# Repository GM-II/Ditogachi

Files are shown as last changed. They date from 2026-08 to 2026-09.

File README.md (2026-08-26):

# Ditogachi

<p align="center">
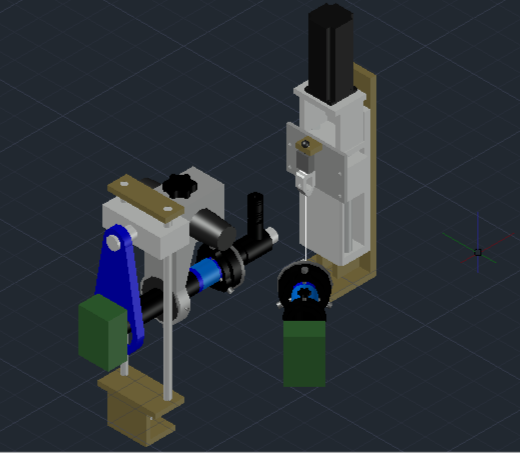
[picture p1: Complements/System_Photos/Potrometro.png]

</p>

## Open-Hardware System for Micrometric Deformation Measurement

This project presents the design and development of an open-hardware system that includes an extensometer capable of accurately measuring mechanical deformations at the micrometric scale, along with a set of open-source algorithms optimized for image analysis and the use of computer vision for the correct interpretation of the acquired data.

The system is intended for laboratory applications, teaching, and research. Priority is given to reproducibility, low cost, and easy access to the materials required for fabrication.

The source codes shared below, together with the referenced links and supporting materials under development, aim to enable anyone to build their own device for the analysis of stress, strain, and failure mechanisms.

This project combines Arduino and Python code.

## System Overview

<p align="center">
  
</p>

<p align="center">
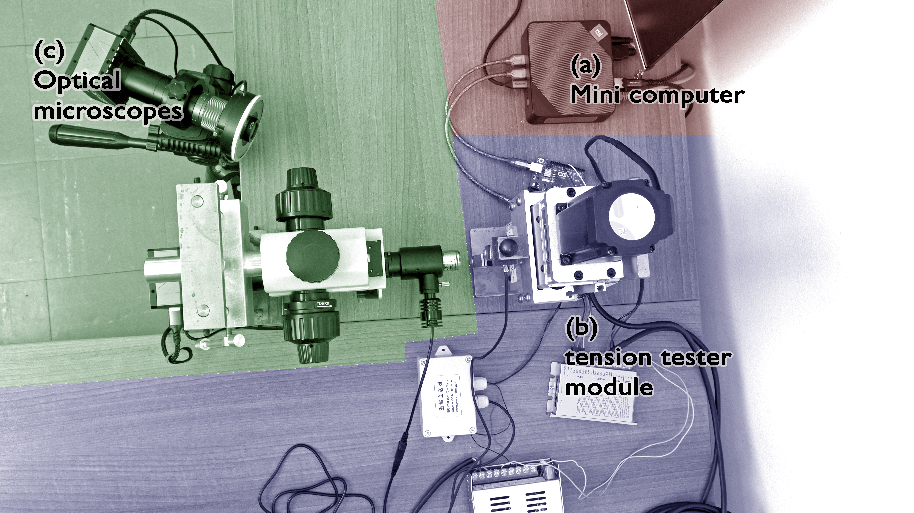
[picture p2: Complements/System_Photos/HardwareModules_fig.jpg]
  
</p>

<p align="center">
  
</p>

<p align="center">
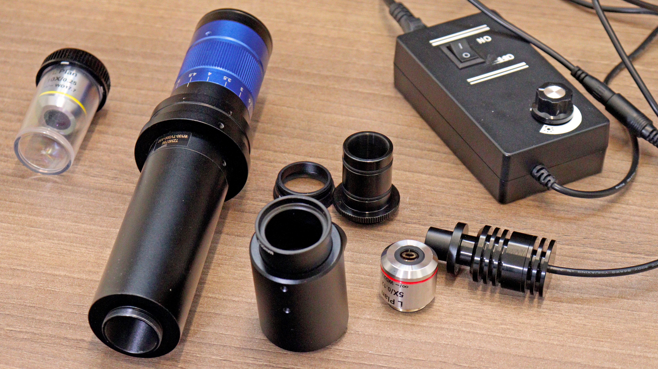
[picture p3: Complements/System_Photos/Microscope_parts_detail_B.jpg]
  
</p>

<p align="center">
  
</p>

*General view of the system, tensile module, microscopy system, and control electronics.*

## Repository content

- [`Build_Instruction`](./Build_Instruction/)
  Step-by-step instructions for the fabrication and assembly of the device.
  
- [`Operation_Instruction`](./Operation_Instruction/)
  Guidelines for proper use of the device, including calibration and safe operation.

- [`Bill_of_materials.md`](./Bill_of_materials.md)  
  Complete list of components, suppliers, and estimated costs.

- [`Software`](./Software/)
  Source code and scripts for data acquisition and analysis. Versions range from early alpha releases to version 2.0 of the code.

- [`Design_Files`](./Design_Files/) 
  Technical standards and references used in the design process (.stl files).

- [`Results`](./Results/)
  Experimental results obtained for the samples: force–elongation plots for each sample material.

- [`Complements/`](./Complements/)
  
  Supplementary documentation, including load cell characterization results and additional photographs of the system.

- [`Research_Output/`](./Research_Output/)
  
  Thesis manuscript and appendices documenting the first reported version of the system, provided as background and historical reference.

## Requirements

- 3D printer / access to a mechanical fabrication workshop
- Electronic components listed in the BOM
- Basic knowledge of instrumentation and electronics
- Software: Python (with required libraries: cv2, numpy, time, openpyxl, datetime, serial, os) / Arduino

## Instructions 

1. Consult the file [`Bill_of_materials.md`](./Bill_of_materials.md)).
2. Follow the construction instructions provided in [`Build_Instruction`](./Build_Instruction/).
3. Carefully review [`Operation_Instruction`](./Operation_Instruction/)) before operating the device.
4. Upload the firmware (.ino files) to the microcontrollers and run the Python scripts included in [`Software`](./Software/).

## Quick operation guide

1. **Setup**  
   Ensure the device is correctly assembled and all electrical connections
   are properly secured.

2. **Power on**  
   Connect the power supply and switch on the system.

3. **Operation**  
   Place the sample according to the specified orientation and initiate
   the measurement sequence using the provided software.

4. **Data acquisition**  
   Monitor real-time data on the interface and save measurement files
   after completion.

5. **Shutdown**  
   Stop the measurement, power off the device, and disconnect the power supply.

⚠️ **Important:**  
This section provides a high-level overview only.  
For calibration, safety precautions, and detailed operation procedures,
refer to [`Operation_instruction`](./Operation_instruction/).

## Project Status

- Functional prototype validated for laboratory use.
- Documentation is currently under development.
- Open to contributions.

## Licenses


###### Documentation
<a href="https://github.com/GM-II/Ditogachi">Ditogachi's Documentation</a> © 2026 by <a href="https://github.com/GM-II">GM-II</a> is licensed under <a href="https://creativecommons.org/licenses/by/4.0/">Creative Commons Attribution 4.0 International</a>

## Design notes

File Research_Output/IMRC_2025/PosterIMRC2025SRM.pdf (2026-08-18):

Heterogeneous Material Stress-Strain and Failure Analysis.

## Computer vision system for non-contact stress-strain assessment and failure mechanism analysis in tension tests of materials with heterogeneous microstructure

## Adquisición

Subsistema óptico de resolución alta: Zoom óptico con lente Barlow, cámara digital de alta velocidad y software de captura en tiempo real. Subsistema óptico microscópico: Microscopía con lentes de aumento variable y sistema de iluminación control de intensidad.

# Abstract

In this contribution we present a tension test system comprised of an open hardware testing machine and a set of open-source computer vision algorithms for non-contact stress-strain assessment.
The hardware is a homemade equipment customized for micro-tension experiments with maximum load of 50 kgf. We present a detailed set of building instructions, where the cost of the materials bill is around 1500 USD, a set of experiments evaluating the machine performance and limitations, mechanical test characterization for a wide set of materials, including those with heterogeneous microstructure distribution as well as reference materials for interlaboratory comparison.

# Materials and Methods

## System Environments

The overall system was designed to integrate three environments that, when coupled and synchronized, form a unified whole capable of performing deformation analysis and failure mechanism assessments: • Uniaxial tension generation and hardware control. • Image acquisition

- Computational control

Figure 1: System Environments.

# Results and Analysis

# Conclusion

- The prototype is an innovative alternative for the analysis of heterogeneous materials. Its results are promising, though optimization is required to expand its application across different study contexts. It shows strong potential for analyzing deformations and failure mechanisms.

# Acknowledgements

The authors acknowledge the structural support provided by the Universidad Nacional de Colombia (National University of Colombia), Colombia. We also thank Edison Ferney Abril Romero and Jhon Jairo Fajardo Toledo for their generous help in the development of the mechanical system, José Alfredo Gómez Mateus for his guidance on the basic understanding of the DIC protocols, and Serena Triviño Saenz for her collaboration in the experimental method characterization and validation. This Project belongs to the research hub with Hermes code 60225.

# References

For complete project references, scan the QR code.

Authors: Santiago Rosas Mogollón - srosasm@unal.edu.co Carlos Mario Garzón Ospina - cmgarzono@unal.edu.co Grupo de Microscopía Electrónica - Programa de Pregrado en Física

Figure 2: Assay on cupper sample.

Figure 3: Test specimens: Stainless steel on copper, tissue scaffolds, and biopolymers (from left to right).

Below, Figures 4, 5, and

### 6 show both the interface

operation and the results
of deformations and
failure mechanisms.

Figure 6: Elongation Tension Curves.

Figure 5: Failure mechanism in copper with steel couting.

Figure 4: Stress-strain assay in bovine collagen scaffold.

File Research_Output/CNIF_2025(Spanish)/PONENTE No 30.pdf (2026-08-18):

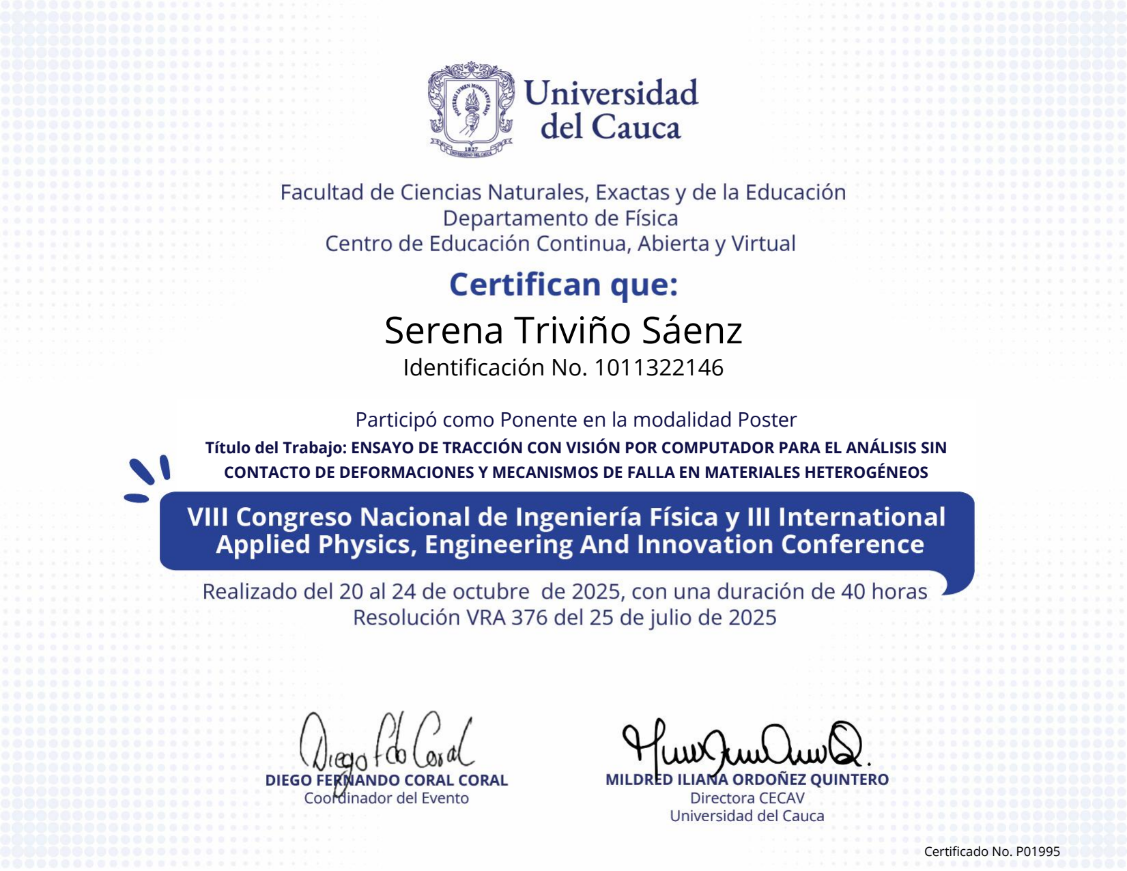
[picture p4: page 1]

# Serena Triviño Sáenz

## Identificación No. 1011322146

Certificado No. P01995

### Participó como Ponente en la modalidad Poster

Título del Trabajo: ENSAYO DE TRACCIÓN CON VISIÓN POR COMPUTADOR PARA EL ANÁLISIS SIN CONTACTO DE DEFORMACIONES Y MECANISMOS DE FALLA EN MATERIALES HETEROGÉNEOS

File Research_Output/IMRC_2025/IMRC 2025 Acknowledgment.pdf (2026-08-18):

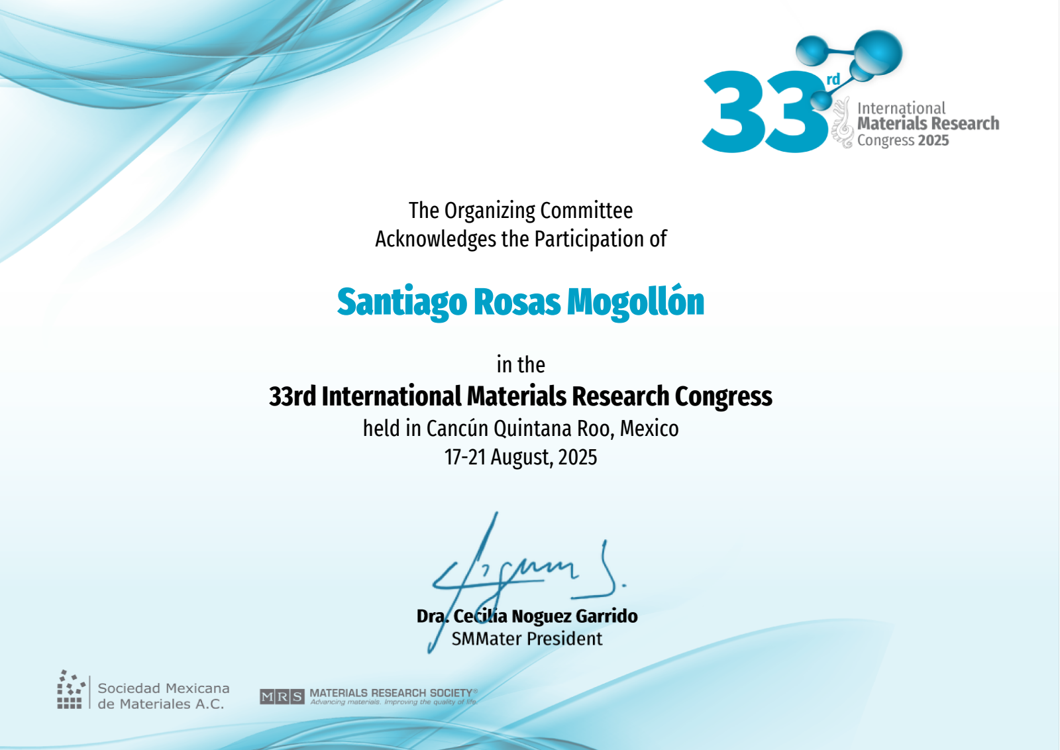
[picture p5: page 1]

The Organizing Committee
Acknowledges the Participation of

## Santiago Rosas Mogollón

in the

### 33rd International Materials Research Congress

held in Cancún Quintana Roo, Mexico 17-21 August, 2025

Powered by TCPDF (www.tcpdf.org)

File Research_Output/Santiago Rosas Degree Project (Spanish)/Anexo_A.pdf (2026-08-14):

## Anexo A

Santiago Rosas Mogollón

Marzo 2025

## 1. Control y Configuración del Motor y Driver

Para el control tanto del motor como del Driver se realizó una revisión a fondo de los manuales puestos a disposición del público por Rtelligent. En ellos se especifican tanto el modo de operación de las palancas del Driver como las diferentes opciones de micro pasos que se pueden obtener con las combinaciones de Estados encendido o apagado de los mismos además de este se especifican las conexiones del motor del Driver qué fuente requieran el tipo de señal que aceptan especificaciones técnicas y una guía sobre las señales de salida del Driver.[1][2]

### 1.1. Configuración de las Palancas de Selección (Switches)

Sobre las palancas de la sw5 a la sw8 modifican el modo de operación del Driver:

La palanca sw5 modifica la dirección del motor manualmente.

La palanca sw6 apaga o enciende la función de filtro de pulso.

La palanca sw7 selecciona el modo de pulso que se va a tomar si es un modo de pulso simple o un modo de pulso doble. Para el montaje se utilizó el modo de pulso simple.

La palanca sw8 controla si el motor está en modo lazo cerrado o abierto, el lazo abierto puede ser utilizado para una prueba inicial del motor.

Así mismo, las palancas de la sw1 hasta la sw4 permiten controlar los pulsos por Revolución, que no son más que los micro pasos en los que se pueden dividir los pasos nominales del motor. Para el motor 57A3ED que se utilizó, los pasos nominales eran 200, es decir, se necesitan 200 pulsos para dar un giro completo. Con respecto a la configuración utilizada de pulsos/rev, se seleccionó la mayor posible de 40,000 pulsos/rev, según como se indica tanto en el manual del Driver T60 como en la placa del mismo donde se encuentran todas las configuraciones posibles del Driver.

### 1.2. Conexiones del Sistema

En cuanto a las conexiones, basta con entender las conexiones del Driver para conseguir realizar el correcto ensamble del sistema. El Driver se divide en cuatro secciones de conexión:

1. VDC / Alimentación: Corresponde a la conexión hacia la fuente de alimentación. En este montaje se usó una fuente Drok de voltaje variable a 24 voltios.
2. Motor: Es la conexión directa con el stepper servomotor 57A3ED. Esta puede ser encontrada en la calcomanía de información del motor. En este caso la conexión es:

A+: Rojo

A-: Azul

B+: Verde

B-: Negro

3. Encoder: Tiene una conexión estandarizada para el Driver, la cual está distribuida de la siguiente manera:

EB+: Verde

EB-: Amarillo

EA+: Marrón

EA-: Blanco

Vcc: Rojo

GND: Azul

4. Signal: Son las conexiones para el control del pulso suministrado, el cual controla el avance del motor y su dirección. La conexión realizada fue:

PUL+ , DIR+ y ENA- al pin 9 PWM del Arduino Uno.

PUL- , DIR- y ENA+ al pin GND digital del mismo Arduino Uno.

Este Arduino fue programado con el código presentado en el Apéndice A.

### 1.3. Parámetros de Velocidad y Desplazamiento

Finalmente, la velocidad del motor se estableció en la más baja posible, la cual corresponde a 0,005 revoluciones por segundo. Dado el paso del actuador lineal de 5 mm por revolución, se obtiene un desplazamiento relativo entre mordazas de 0,025 mm cada segundo. Esto se logró generando un pulso cuadrado de 250 Hz y un 50 % de ciclo de trabajo.

## Apéndice A: Código Arduino

El siguiente código fue implementado en la plataforma Arduino para el control de la frecuencia de los pulsos enviados al Driver:

1 | // Definir el pin donde se g e n e r a r | el pulso
2 | const int pinPulso = 9; | // Pin 9 es v l i d o en Arduino Uno
3 | // Variable para almacenar la frecuencia deseada (en Hz)
4 | int frecuencia = 0; | // Frecuencia inicial

5

6
7 | // Variable para almacenar el p e r o d o del pulso (en microsegundos )
8 | unsigned long periodo ;

9
10 | void setup () {
11 | // Configurar el pin como salida
12 | pinMode ( pinPulso , OUTPUT ) ;
13 | // Iniciar la c o m u n i c a c i n serial
14 | Serial . begin (115200) ;
15 | // Calcular el p e r o d o inicial
16 | periodo = 1000000 / frecuencia ; | // 1 segundo = 1 ,000 ,000
microsegundos

17 }

18
19 | void loop () {
20 | if ( Serial . available () > 0) {
21 | String input = Serial . readStringUntil (’\n’) ;

22
23 | if ( input == " STOP ") {
24 | // Detener completamente los pulsos
25 | digitalWrite ( pinPulso , LOW ) ;
26 | } else {
27 | // Procesar como frecuencia
28 | frecuencia = input . toInt () ;
29 | if ( frecuencia > 0) {
30 | periodo = 1000000 / frecuencia ;
31 | }
32 | }
33 | }

34
35 | if ( frecuencia > 0) { | // Solo generar pulsos si frecuencia > 0
36 | digitalWrite ( pinPulso , HIGH ) ;
37 | delayMicroseconds ( periodo / 2) ;
38 | digitalWrite ( pinPulso , LOW ) ;
39 | delayMicroseconds ( periodo / 2) ;
40 | } else {
41 | digitalWrite ( pinPulso , LOW ) ;
42 | }
43 | }

## Referencias

[1] Rtelligent. | 2 phase closed loop stepper drive factory - china 2 phase closed
loop stepper drive manufacturers, suppliers. | https://www.rtelligentglobal.com/
2-phase-closed-loop-stepper-drive-oplen-loop-stepper-system/. Accedido: 11 de marzo de 2025.
[2] Rtelligent. | Wholesale | phase | closed | loop | stepper | motor | 57 | se-
ries | factory | and | suppliers. | https://www.rtelligentglobal.com/
phase-closed-loop-stepper-motor-57-series-product/. | Accedido: 11 de marzo
de 2025.

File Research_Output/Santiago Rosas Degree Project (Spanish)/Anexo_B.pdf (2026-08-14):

Anexo B: Caracterización de la Celda de Carga de 50 Kg.

### 1. Introducción

Este anexo describe la metodología empleada para caracterizar la celda de carga de 50 Kg integrada en la máquina. El análisis incluye la determinación de la relación entre la fuerza aplicada y la señal de salida, así como la evaluación de la linealidad en el rango de trabajo. Los resultados garantizan la precisión de las mediciones obtenidas durante las pruebas experimentales.

### 2. Materiales y Métodos

### 2.1. Equipo Utilizado

- Celda de carga: Modelo DYLY106, con una capacidad nominal máxima de 50 kg, una salida nominal de 2.0mV/V, y una precisión de +/- 0.1%.
- Transmisor amplificador de celda de carga: Se seleccionó un modelo WXD-D70 (JY-S60), optimizado para este tipo de celda de carga. El dispositivo acepta una señal de entrada con sensibilidad de sensor de 2.0 mV/V hasta 20mV y proporciona una salida DC de 0–5V / 0–10 V / 4–20 mA
- Fuente de alimentación: 24 V.
- Sistema de adquisición de datos: interfaz basada en Arduino con software de caracterización personalizado.
- Una prensa vertical con una carga de compresión inicial de 4.04 Kg.
- Un gancho de 0.76 Kg.
- Patrones de calibración: un conjunto de pesas de precisión de 1, 2, 4 y 10 Kg, previamente verificadas mediante una báscula digital calibrada (OHAUS Ranger 3000).

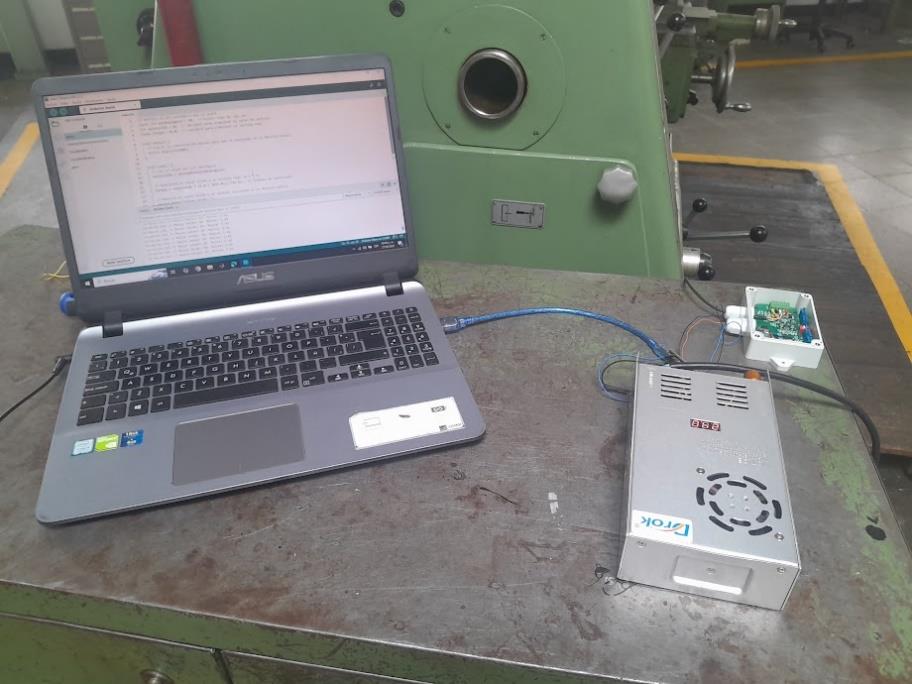
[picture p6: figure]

Fig 1. Hardware para la caracterización de la celda de carga.

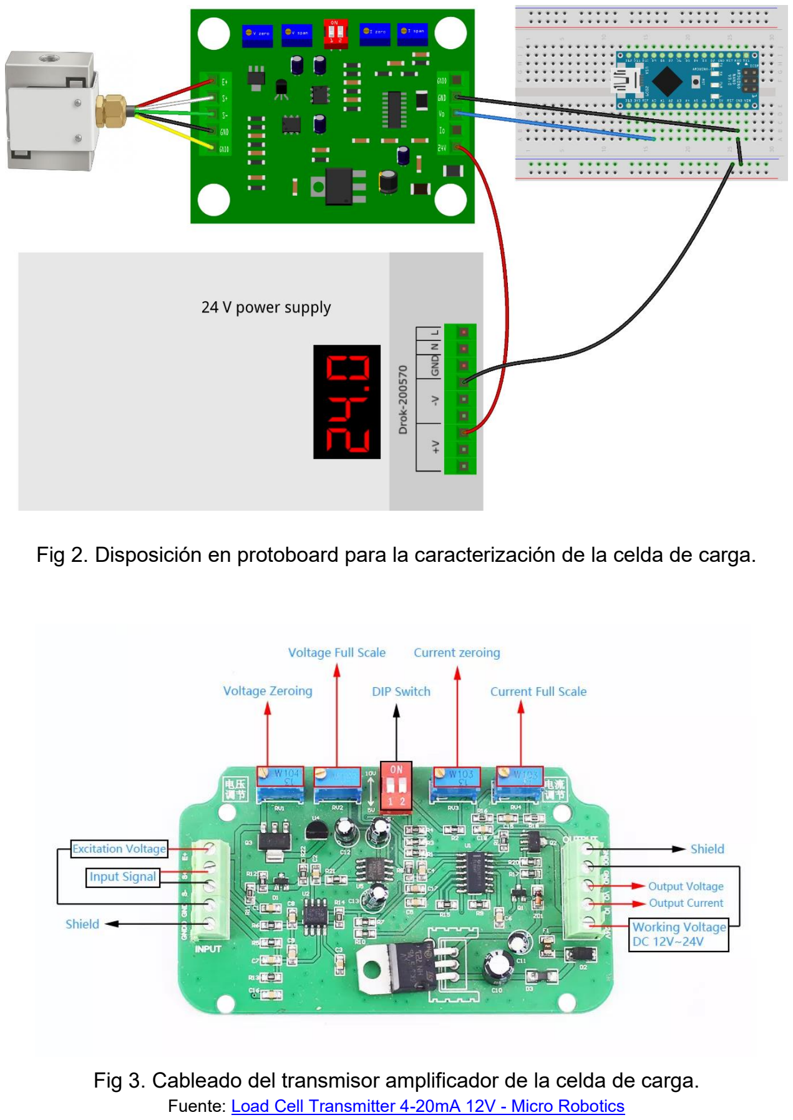
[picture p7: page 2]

Fig 2. Disposición en protoboard para la caracterización de la celda de carga.

Fig 3. Cableado del transmisor amplificador de la celda de carga.
Fuente: Load Cell Transmitter 4-20mA 12V - Micro Robotics (https://www.robotics.org.za/JY-S60-12V)

### 2.2. Procedimiento Experimental

Siguiendo las instrucciones de cableado de todos los componentes, la celda de carga fue conectada al amplificador y a la placa Arduino Nano, la cual estaba conectada a un PC para la adquisición de datos (ver Fig. 1 a 3).
Se implementó un sistema de tracción vertical a compresión, incorporando un mecanismo de suspensión y la prensa. Luego se aplicaron cargas incrementales utilizando las pesas de calibración, ascendiendo hasta el 80% de la capacidad máxima de la celda de carga. Para cada medición, se registró el voltaje de salida (ver Fig. 4).

Se aplicó el cálculo del voltaje de span, proporcionado por ATO en el Manual de Usuario del Transmisor de Celda de Carga [Load-cell-transmitter-user-manual-ATO-LCTR-OA]: (https://www.ato.com/Content/doc/Load-cell-transmitter-user-manual-ATO-LCTR-OA.pdf)

Voltaje de span = Peso del objeto / Capacidad de la celda de carga * 5V

Esta fórmula fue integrada en el software de análisis de datos basado en Arduino para generar la caracterización específica detallada en este documento. Finalmente, los datos adquiridos fueron ajustados mediante regresión lineal.

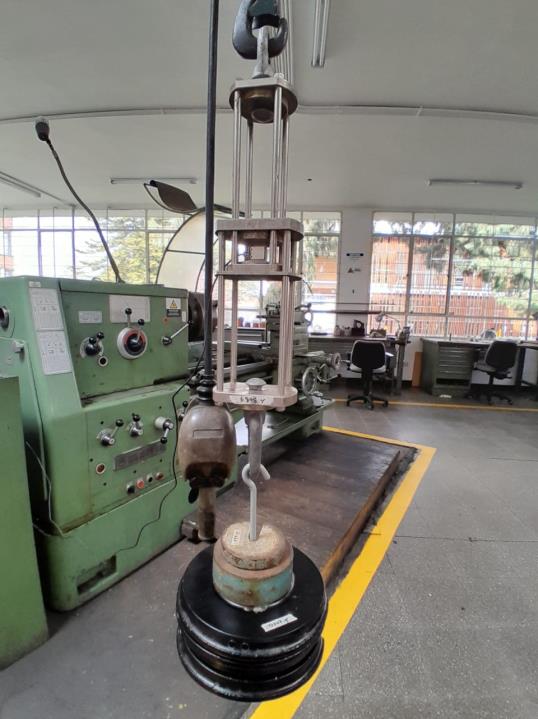
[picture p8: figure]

Fig. 4. Incremento gradual de las pesas de calibración

### 3. Resultados

La caracterización proporcionó la relación entre el voltaje de salida y la carga de peso aplicada, y también confirma que la celda de carga cumple con los requisitos de precisión y repetibilidad necesarios para el proyecto.

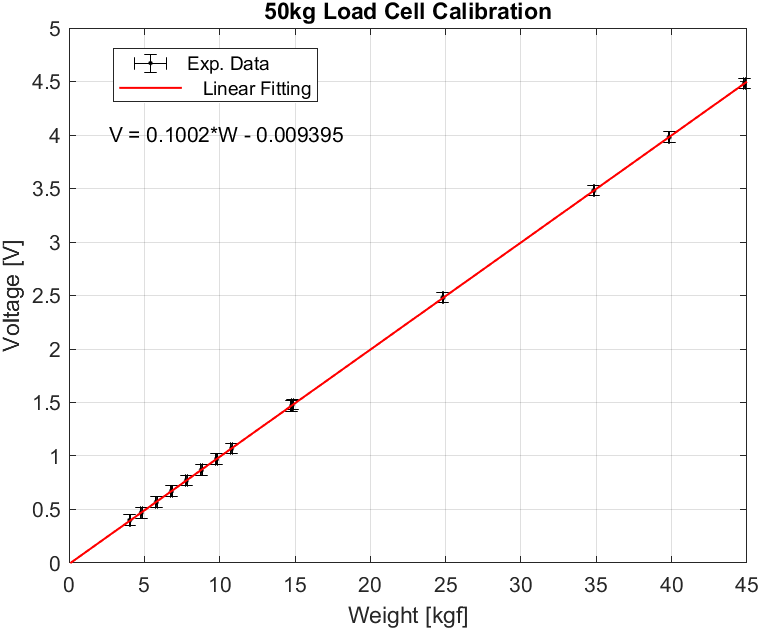
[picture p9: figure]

Fig. 5. Ajuste lineal del voltaje de salida en función del peso.

Como se puede observar en la Fig. 5, la relación Voltaje de salida/Carga es de 0.1002 V/kgf o 0.1002 V/kg +/- 1%. Al hacer la conversión a N/V (ajustada para la aceleración gravitacional de Bogotá de 9.774 m/s²), esta se convierte en 97.54 N/V +/- 3%, siendo esta la relación final que se configurará en el software de adquisición de datos basado en Arduino. El R-cuadrado es 1 en el rango evaluado, lo que demuestra la linealidad de la celda de carga.

Tanto para la caracterización como para los experimentos, se recomienda no exceder el 90% de la capacidad máxima de carga, para evitar pérdidas de precisión o de linealidad en las mediciones, o incluso dañar la celda de carga.

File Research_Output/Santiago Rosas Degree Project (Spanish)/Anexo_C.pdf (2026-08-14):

# Anexo C

### Santiago Rosas Mogollón

### Marzo 2025

## 1. Fundamentos de Correlación Digital de Imágenes (DIC)

La Correlación Digital de Imágenes (DIC, por sus siglas en inglés, Digital Image Correlation) es una técnica óptica metrológica no invasiva que permite medir campos de desplazamiento y deformación en la superficie de un material bajo carga. El principio básico de la DIC radica en el seguimiento de patrones espaciales de intensidad de escala de grises distribuidos sobre la muestra a lo largo de una serie de fotogramas secuenciales.
El proceso general consta de los siguientes pilares matemáticos y algorítmicos:

Extracción de Características (Feature Detection): Identificación de puntos de interés únicos en la imagen invariantes a transformaciones afines, ruido y cambios de iluminación.

Descripción de Características (Feature Description): Generación de un vector numérico (descriptor) que codifica la información visual del entorno del punto de interés.

Emparejamiento (Matching): Minimización de una métrica de distancia espacial o binaria entre los vectores descriptores de una imagen de referencia I0 (estado sin deformar) y una imagen objetivo It (estado deformado).

## 2. Análisis Comparativo de Algoritmos: SIFT vs. ORB

Para el desarrollo experimental de este sistema de medición de deformaciones, se implementaron y evaluaron dos de los algoritmos más representativos en el estado del arte de la visión por computadora: SIFT (Scale-Invariant Feature Transform) y ORB (Oriented FAST and Rotated BRIEF).

### 2.1. SIFT (Scale-Invariant Feature Transform)

SIFT extrae puntos clave detectando extremos en un espacio de escalas construido mediante funciones Gaussianas (DoG, Difference of Gaussians). Su descriptor consiste en un vector de 128 dimensiones basado en gradientes locales de orientación de la imagen. Ventajas: Extrema robustez ante cambios drásticos de escala, rotaciones complejas y variaciones afines de iluminación. Desventajas: Alto costo computacional debido al cálculo de operaciones en coma flotante sobre un vector denso, lo que limita su viabilidad en sistemas de procesamiento en tiempo real de recursos limitados.

### 2.2. ORB (Oriented FAST and Rotated BRIEF)

ORB surge como una alternativa eficiente y libre de patentes. Combina el detector de esquinas FAST (Features from Accelerated Segment Test) modificado para añadir orientación, junto con el descriptor binario BRIEF (Binary Robust Independent Elementary Features) rotado analíticamente. Ventajas: En lugar de operar con gradientes vectoriales flotantes, ORB construye una cadena de bits (un string binario) mediante comparaciones directas de intensidad de píxeles. Esto permite evaluar las distancias de emparejamiento utilizando la distancia de Hamming a nivel de compuertas lógicas, acelerando exponencialmente el proceso. Es ideal para el monitoreo concurrente en sistemas real-time.

## 3. Postprocesado (SIFT)

El primer script desarrollado tiene como finalidad realizar un análisis estático de alta precisión comparando el estado inicial (pre-deformación) y final de la probeta mediante el uso secuencial de SIFT.

### 3.1. Flujo Lógico y Funciones Críticas

1. Lectura en Escala de Grises: Se cargan los archivos a2.png y a5.png en arreglos matriciales bidimensionales omitiendo los canales RGB (cv2.IMREAD GRAYSCALE) para optimizar el cómputo de gradientes.
2. Detección y Cómputo: Mediante sift.detectAndCompute() se obtienen los puntos clave (keypoints) y sus respectivos descriptores.
3. Emparejamiento por Fuerza Bruta (BFMatcher): Se inicializa un emparejador que evalúa de forma exhaustiva cada descriptor de la primera imagen contra todos los de la segunda mediante una distancia euclidiana L2.
4. Filtro de Ratio de Lowe: Para discriminar emparejamientos ambiguos o falsos positivos causados por texturas repetitivas, se aplica el criterio de Lowe:
dmatch 1 < 0,75 × dmatch 2 | (1)

Donde solo se aceptan los puntos cuyo vecino más cercano sea significativamente más próximo que el segundo vecino más cercano.

5. Cálculo Euclidiano del Desplazamiento: Una vez aislados los matches válidos, se extraen las coordenadas espaciales (x, y) en el plano cartesiano del sensor óptico de ambos estados y se calcula la distancia geométrica:

Displacement = p
(xafter − xbefore)

2 + (yafter − ybefore)

2 | (2)

Finalmente, se aplica el operador media aritmética (np.mean) para estimar el desplazamiento promedio global en píxeles del material.

## 4. Tiempo Real (ORB)

El segundo desarrollo responde a la necesidad de adquirir, sincronizar y registrar datos de manera síncrona en tiempo real, operando con dos cámaras independientes de forma simultánea y vinculando mediciones analógicas externas de fuerza. El algoritmo ORB se configuró mediante un ajuste fino de sus coeficientes operativos para equilibrar la densidad de características y la velocidad de cómputo en la Región de Interés (ROI). El parámetro nfeatures=500 restringe la búsqueda a los 500 puntos clave más estables, limitando la carga computacional por ciclo. Para otorgar invariabilidad de escala frente a posibles desplazamientos axiales de las cámaras, se definió un scaleFactor=1.2 estructurado en nlevels=8, lo que genera una pirámide de resolución de 8 capas donde cada nivel se reduce en un 20 % respecto al anterior. El análisis espacial y descarte de ruido en la ROI se controla mediante edgeThreshold=31 y patchSize=31, dimensiones que delimitan el vecindario de píxeles para el cálculo del descriptor binario. La evaluación de los puntos se realiza a través de la métrica scoreType=cv2.ORB HARRIS SCORE, la cual aplica el criterio de la matriz de autodiferencia de Harris para clasificar y ordenar los puntos en función de la agudeza de sus esquinas, en lugar del enfoque FAST puro. Finalmente, los parámetros WTA K=2 y fastThreshold=20 definen, respectivamente, que el descriptor BRIEF realice comparaciones binarias de pares de píxeles orientados y que el umbral de aceptación FAST sea lo suficientemente sensible para capturar texturas sutiles en la superficie del material bajo ensayo

### 4.1. Arquitectura del Sistema en Tiempo Real

El script inicializa un entorno de adquisición concurrente estructurado bajo los siguientes módulos operativos:

Inicialización de Hardware Dual: Se configuran dos instancias de captura de video a una resolución nativa de alta definición (1280 × 720 píxeles). La primera cámara captura el plano macro de deformación (“Camera meso”), mientras que la segunda registra la perspectiva a nivel microscópico (“Camera micro”). Los flujos de video crudos se almacenan en tiempo real en discos locales en formato contenedor MP4 utilizando la biblioteca VideoWriter con códec mp4v y compresión controlada al 80 %.

Selección Dinámica de la Región de Interés (ROI): Al arrancar el bucle principal, se congela el primer fotograma y se despliega una interfaz interactiva de usuario (cv2.selectROI()). Esto permite aislar un cuadrante específico del material donde se concentran los esfuerzos mecánicos, acotando el espacio de cómputo del extractor ORB de manera drástica y descartando el ruido del entorno de fondo.

Mecanismo de Filtrado y Gestión de Ruido: Para blindar las lecturas métricas de la vibración inherente del motor y las fluctuaciones del sensor, se parametriza un umbral de desplazamiento de 1 píxel (displacement threshold). Si el desplazamiento promedio extraído por los vectores de Hamming no supera este límite, el cambio es clasificado como ruido blanco y se conserva el último estado estacionario válido (last valid displacement).

Sincronización Serial y Exportación de Datos: A intervalos constantes controlados de 0,3 segundos (∆t = 300 ms), el algoritmo interrumpe la captura visual para decodificar las tramas de datos del puerto de comunicación serial COM4 conectado al microcontrolador Arduino. Se extraen dos variables críticas: el valor analógico crudo y la fuerza calculada en Newtons. Estos parámetros se empaquetan instantáneamente junto con una marca temporal de precisión milimétrica (Timestamp) dentro de una hoja de cálculo relacional estructurada con la biblioteca openpyxl.

Interrupción de Flujo y Control de Referencias: El operador cuenta con control de flujo por teclado. Presionar la tecla ’p’ conmuta el sistema a un estado de suspensión visual (Pausa) que detiene la grabación en archivo. Al reanudar la marcha, el script obliga de manera automática a redefinir una nueva ROI y calcular un nuevo vector descriptor de referencia espacial, permitiendo un análisis de deformación por etapas acumulativas sin arrastrar errores de deriva.

## Apéndice I: Código Fuente del Script de Postprocesado (SIFT)

1 | import cv2
2 | import numpy as np

3
4 | # Cargar imagenes antes y despues de la deformacion
5 | image_before = cv2 . imread (’a2.png ’, cv2 . IMREAD_GRAYSCALE )
6 | image_after = cv2 . imread (’a5.png ’, cv2 . IMREAD_GRAYSCALE )

7
8 | # Inicializa SIFT
9 | sift = cv2 . SIFT_create ()

10
11 | # Detecta puntos caracteristicos y descriptores en ambas imagenes
12 | keypoints_before , descriptors_before = sift . detectAndCompute (
image_before , None )
13 | keypoints_after , descriptors_after = sift . detectAndCompute ( image_after ,
| None )

14
15 | # Empareja descriptores usando el matcher BF (Brute - Force )
16 | bf = cv2 . BFMatcher ()
17 | matches = bf . knnMatch ( descriptors_before , descriptors_after , k =2)

18
19 | # Filtra matches usando el ratio de Lowe
20 | good_matches = []
21 | for m , n in matches :
22 | if m . distance < 0.75 * n . distance :
23 | good_matches . append ( m )

24
25 | # Dibuja los matches
26 | output_image = cv2 . drawMatches ( image_before , keypoints_before ,
image_after , keypoints_after , good_matches , None , flags =2)

27
28 | # Redimensionar la imagen de salida para que quepa en la ventana
29 | scale_percent = 50 | # Porcentaje del tamano original
30 | width = int ( output_image . shape [1] * scale_percent / 100)
31 | height = int ( output_image . shape [0] * scale_percent / 100)
32 | dim = ( width , height )
33 | resized_output_image = cv2 . resize ( output_image , dim , interpolation = cv2 .
| INTER_AREA )

34
35 | # Crear una ventana con un tamano especifico
36 | cv2 . namedWindow (’Matches ’, cv2 . WINDOW_NORMAL )
37 | cv2 . resizeWindow (’Matches ’, width , height )

38
39 | # Mostrar los matches
40 | cv2 . imshow (’Matches ’, resized_output_image )
41 | cv2 . waitKey (0)
42 | cv2 . destroyAllWindows ()

43
44 | # Calcula desplazamientos
45 | displacements = []
46 | for match in good_matches :
47 | pt_before = keypoints_before [ match . queryIdx ]. pt
48 | pt_after = keypoints_after [ match . trainIdx ]. pt
49 | displacement = np . sqrt (( pt_after [0] - pt_before [0]) **2 + ( pt_after
[1] - pt_before [1]) **2)
50 | displacements . append ( displacement )

51

52 | # Calcula la deformacion promedio
53 | average_displacement = np . mean ( displacements )
54 | print ( f" Desplazamiento promedio : { average_displacement } pixeles ")

## Apéndice II: Código Fuente del Script en Tiempo Real (ORB)

1 | import cv2
2 | import numpy as np
3 | import time
4 | from openpyxl import Workbook
5 | from datetime import datetime
6 | import serial
7 | # C o n f i g u r a c i n de v i s u a l i z a c i n
8 | DISPLAY_WIDTH = 640
9 | DISPLAY_HEIGHT = 480
10 | # r e s o l u c i n
11 | RESOLUCION = (1280 , 720)
12 | CALIDAD = 80
13 | # Inicializar ORB
14 | orb = cv2 . ORB_create ( nfeatures =500 ,
15 | scaleFactor =1.2 ,
16 | nlevels =8 ,
17 | edgeThreshold =31 ,
18 | firstLevel =0 ,
19 | WTA_K =2 ,
20 | scoreType = cv2 . ORB_HARRIS_SCORE ,
21 | patchSize =31 ,
22 | fastThreshold =20)

23
24 | # Inicializar la c m a r a principal
25 | cap = cv2 . VideoCapture (1) | # Usar la c m a r a predeterminada ( c m a r a web
| )

26
27 | # Inicializar la segunda c m a r a
28 | cap2 = cv2 . VideoCapture (0) | # Usar la segunda c m a r a ( ajusta el | ndice
s e g n tu c o n f i g u r a c i n )

29
30 | # Verificar si las c m a r a s se abrieron correctamente
31 | if not cap . isOpened () :
32 | print (" Error : No se pudo abrir la c m a r a principal .")
33 | exit ()

34
35 | if not cap2 . isOpened () :
36 | print (" Error : No se pudo abrir la segunda c m a r a .")
37 | exit ()
38 | # Configurador de r e s o l u c i n a 1080 p para ambas camaras
39 | cap .set ( cv2 . CAP_PROP_FRAME_WIDTH , RESOLUCION [0])
40 | cap .set ( cv2 . CAP_PROP_FRAME_HEIGHT , RESOLUCION [1])

41
42 | cap2 .set ( cv2 . CAP_PROP_FRAME_WIDTH , RESOLUCION [0])
43 | cap2 .set ( cv2 . CAP_PROP_FRAME_HEIGHT , RESOLUCION [1])

44
45 | # Obtener la r e s o l u c i n del frame de la c m a r a principal
46 | frame_width = int ( cap . get ( cv2 . CAP_PROP_FRAME_WIDTH ) )
47 | frame_height = int ( cap . get ( cv2 . CAP_PROP_FRAME_HEIGHT ) )
48 | fps = int ( cap . get ( cv2 . CAP_PROP_FPS ) ) # Cuadros por segundo ( ajustar
| s e g n la c m a r a )

49
50 | # Obtener la r e s o l u c i n del frame de la segunda c m a r a
51 | frame_width2 = int ( cap2 . get ( cv2 . CAP_PROP_FRAME_WIDTH ) )
52 | frame_height2 = int ( cap2 . get ( cv2 . CAP_PROP_FRAME_HEIGHT ) )
53 | fps2 = int ( cap2 . get ( cv2 . CAP_PROP_FPS ) )

54 | # Inicializar VideoWriter para guardar el video de la c m a r a principal
55 | video_output = cv2 . VideoWriter (’ salida_video_macro .mp4 ’, cv2 .
VideoWriter_fourcc (* ’mp4v ’) , fps , RESOLUCION )
56 | video_output .set ( cv2 . VIDEOWRITER_PROP_QUALITY , CALIDAD )
57 | # Inicializar VideoWriter para guardar el video de la segunda c m a r a
58 | video_output2 = cv2 . VideoWriter (’ salida_video_micro .mp4 ’, cv2 .
VideoWriter_fourcc (* ’mp4v ’) , fps2 , RESOLUCION )
59 video_output2 .set ( cv2 . VIDEOWRITER_PROP_QUALITY , CALIDAD )

60
61 | # Variables para almacenar el frame de referencia
62 | reference_frame = None
63 | reference_keypoints = None
64 | reference_descriptors = None
65 | roi = None | # Variable para almacenar la ROI

66
67 | # Variable para controlar el tiempo
68 | last_time = time . time ()
69 | interval = 0.3 | # Intervalo de 0.3 segundo

70
71 | # Umbral para ignorar desplazamientos pequenos (en pixeles )
72 | displacement_threshold = 1 | # Ignorar desplazamientos menores a 1 pixel

73
74 | # Crear un archivo Excel para guardar los datos
75 | wb = Workbook ()
76 | ws = wb . active
77 | ws . title = " D e f o r m a c i n "
78 | ws . append ([" Timestamp ", " Desplazamiento ( p x e l e s )", " Valor l e d o ", "
Newtons ", " Tiempo arduino ", " Tiempo arduino date ", " Tiempo de ciclo ", " Tiempo final "]) # Encabezados

79
80 | # Variable para controlar la pausa
81 | paused = False

82

83

84
85 | # F u n c i n para capturar el frame de referencia y seleccionar la ROI
86 | def capture_reference_frame () :
87 | global reference_frame , reference_keypoints , reference_descriptors ,
roi
88 | ret , frame = cap . read ()
89 | if not ret :
90 | print (" Error : No se pudo capturar el frame de referencia .")
91 | return False

92
93 | # Mostrar el frame y permitir al usuario seleccionar la ROI
94 | roi = cv2 . selectROI (" Selecciona la ROI ", frame , fromCenter = False ,
showCrosshair = True )
95 | cv2 . destroyWindow (" Selecciona la ROI ") | # Cerrar la ventana de
s e l e c c i n de ROI

96
97 | # Recortar el frame de referencia s e g n la ROI
98 | reference_frame = cv2 . cvtColor ( frame , cv2 . COLOR_BGR2GRAY )
99 | reference_frame = reference_frame [int ( roi [1]) :int ( roi [1] + roi [3]) ,
int( roi [0]) :int( roi [0] + roi [2]) ]

100
101 | # Detectar puntos c a r a c t e r s t i c o s y descriptores en la ROI
102 | reference_keypoints , reference_descriptors = orb . detectAndCompute (
reference_frame , None )

103 | if reference_descriptors is None :
104 | print (" Error : No se pudieron calcular los descriptores de
referencia .")
105 | return False
106 | print (" Frame de referencia capturado y ROI seleccionada .")
107 | return True

108
109 | # Capturar el frame de referencia y seleccionar la ROI inicial
110 | if not capture_reference_frame () :
111 | cap . release ()
112 | cap2 . release ()
113 | cv2 . destroyAllWindows ()
114 | exit ()

115
116 | # Variable para almacenar el | ltimo | desplazamiento v l i d o
117 | # Variable para controlar el tiempo
118 | last_time = time . time ()
119 | interval = 0.2 | # Intervalo de 0.1 segundo
120 | last_valid_displacement = 0.0
121 | # Configura el puerto serial ( ajusta el puerto y el baud rate s e g n tu
| c o n f i g u r a c i n )
122 | newtons = 0.0
123 | valor_leido = 0.0
124 | puerto_serial = serial . Serial (’COM4 ’, 115200 , timeout =1) # Cambia ’COMX ’
| por el puerto correcto
125 | print ( datetime . now () . strftime (" %Y- %m- %d %H: %M: %S. %f") )
126 | print ( time . time () )
127 | while True :
128 | time_date_ardu = datetime . now () . strftime (" %Y- %m- %d %H: %M: %S. %f")
129 | time_ardu = time . time ()
130 | # Capturar un frame de la c m a r a principal
131 | ret , frame = cap . read ()
132 | if not ret :
133 | print (" Error : No se pudo capturar el frame de la c m a r a
| principal .")
134 | break
135 | frame_display = cv2 . resize ( frame , ( DISPLAY_WIDTH , DISPLAY_HEIGHT ) )
136 | # Capturar un frame de la segunda c m a r a
137 | ret2 , frame2 = cap2 . read ()
138 | if not ret2 :
139 | print (" Error : No se pudo capturar el frame de la segunda c m a r a
| .")
140 | break
141 | frame2_display = cv2 . resize ( frame2 , ( DISPLAY_WIDTH , DISPLAY_HEIGHT ) )
142 | # Dibujar la ROI en el frame de la c m a r a principal para
v i s u a l i z a c i n (no se guarda en el video )
143 | frame_with_roi = frame . copy ()
144 | if roi is not None :
145 | cv2 . rectangle ( frame_with_roi , (int ( roi [0]) , int ( roi [1]) ) , (int (
roi [0] + roi [2]) , int( roi [1] + roi [3]) ) , (0 , 255 , 0) , 2)

146
147 | # Mostrar el estado de pausa en la ventana de la c m a r a principal
148 | if paused :
149 | cv2 . putText ( frame_with_roi , " PAUSADO ", (10 , 50) , cv2 .
FONT_HERSHEY_SIMPLEX , 1 , (0 , 0 , 255) , 2 , cv2 . LINE_AA )

150
151 | # Mostrar el frame con la ROI en tiempo real
152 | cv2 . imshow (’Camera meso ’, frame_with_roi )

153
154 | # Mostrar el frame de la segunda c m a r a en una ventana separada
155 | if paused :
156 | # Si e s t | en pausa , mostrar un mensaje de " PAUSADO " en la
segunda c m a r a
157 | frame2_paused = frame2 . copy ()
158 | cv2 . putText ( frame2_paused , " PAUSADO ", (10 , 50) , cv2 .
FONT_HERSHEY_SIMPLEX , 1 , (0 , 0 , 255) , 2 , cv2 . LINE_AA )
159 | cv2 . imshow (’Camera micro ’, frame2_paused )
160 | else :
161 | # Si no e s t | en pausa , mostrar el frame normal
162 | cv2 . imshow (’Camera micro ’, frame2 )

163
164 | # Guardar el frame original (sin la ROI ) en el video de la c m a r a
principal si no e s t | en pausa
165 | if not paused :
166 | video_output . write ( frame )
167 | video_output2 . write ( frame2 ) | # Guardar el frame de la segunda
c m a r a

168
169 | # Obtener el tiempo actual
170 | current_time = time . time ()

171
172 | # Procesar solo si ha pasado 1 segundo desde el | ltimo
procesamiento y no e s t | en pausa
173 | if not paused and current_time - last_time >= interval :
174 | # Recortar el frame s e g n la ROI
175 | gray = cv2 . cvtColor ( frame , cv2 . COLOR_BGR2GRAY )
176 | gray_roi = gray [int ( roi [1]) :int ( roi [1] + roi [3]) , int ( roi [0]) :
int( roi [0] + roi [2]) ]

177
178 | # Detectar puntos c a r a c t e r s t i c o s y descriptores en la ROI del
frame actual
179 | keypoints , descriptors = orb . detectAndCompute ( gray_roi , None )

180
181 | # Verificar si los descriptores se calcularon correctamente
182 | if descriptors is not None and reference_descriptors is not None
:
183 | # Emparejar descriptores usando BFMatcher
184 | bf = cv2 . BFMatcher ( cv2 . NORM_HAMMING , crossCheck = True )
185 | matches = bf . match ( reference_descriptors , descriptors )

186
187 | # Calcular el desplazamiento promedio en p x e l e s
188 | average_displacement = 0.0 | # Valor predeterminado si no hay
matches
189 | if len ( matches ) > 0:
190 | # Ordenar matches por distancia
191 | matches = sorted ( matches , key = lambda x : x . distance )

192
193 | # Calcular desplazamientos
194 | displacements = []
195 | for match in matches :
196 | pt1 = reference_keypoints [ match . queryIdx ]. pt
197 | pt2 = keypoints [ match . trainIdx ]. pt
198 | dx = pt2 [0] - pt1 [0]
199 | dy = pt2 [1] - pt1 [1]
200 | displacement = np . sqrt ( dx **2 + dy **2)
201 | displacements . append ( displacement )

202
203 | # Calcular el desplazamiento promedio
204 | average_displacement = np . mean ( displacements )

205
206 | # Solo mostrar el desplazamiento si supera el umbral
207 | if average_displacement > displacement_threshold :
208 | print ( f" Desplazamiento promedio : {
average_displacement :.2 f} p x e l e s ")
209 | last_valid_displacement = average_displacement | #
Actualizar el | ltimo | desplazamiento v l i d o
210 | else :
211 | print (" Desplazamiento despreciable ( ruido )")
212 | average_displacement = last_valid_displacement | #
Usar el | ltimo | desplazamiento v l i d o
213 | else :
214 | print ("No se encontraron matches . Usando el | ltimo
desplazamiento v l i d o .")
215 | average_displacement = last_valid_displacement | # Usar
el | ltimo | desplazamiento v l i d o

216
217 | # Dibujar los matches (si los hay )
218 | if len ( matches ) > 0:
219 | ref_resized = cv2 . resize ( reference_frame , ( DISPLAY_WIDTH
// 2 , DISPLAY_HEIGHT // 2) )
220 | current_resized = cv2 . resize ( gray_roi , ( DISPLAY_WIDTH //
2 , DISPLAY_HEIGHT // 2) )
221 | output_frame = cv2 . drawMatches ( ref_resized ,
reference_keypoints , current_resized , keypoints , matches [:50] , None , flags =2)
222 | output_frame = cv2 . resize ( output_frame , ( DISPLAY_WIDTH ,
DISPLAY_HEIGHT // 2) )
223 | cv2 . imshow (’Matches ’, output_frame )
224 | else :
225 | print ("No se pudieron calcular los descriptores . Usando el
ltimo | desplazamiento v l i d o .")
226 | average_displacement = last_valid_displacement | # Usar el
ltimo | desplazamiento v l i d o

227
228 | # Leer datos del Arduino
229 | linea = puerto_serial . readline () . decode (’utf -8 ’) . strip ()
230 | if linea :
231 | partes = linea . split ()
232 | if len ( partes ) >= 5: | # Asegurarse de que hay suficientes
elementos
233 | valor_leido = float ( partes [2]) | # El valor l e d o es el
tercer elemento
234 | newtons = float ( partes [4]) | # Los Newtons son el sexto
elemento
235 | print ( f" Fuerza :{ newtons :.2 f}")
236 | # Guardar el desplazamiento y los datos del Arduino en
el archivo Excel
237 | timestamp = datetime . now () . strftime (" %Y- %m- %d %H: %M: %S. %
f")
238 | finali_time = time . time ()
239 | ws . append ([ timestamp , average_displacement , valor_leido ,
newtons , time_ardu , time_date_ardu , current_time , finali_time ])

240
241 | # Reiniciar el temporizador

242 | last_time = current_time
243 | # Manejar la tecla ’p’ para pausar / continuar
244 | key = cv2 . waitKey (1)
245 | if key & 0 xFF == ord (’p’) :
246 | paused = not paused
247 | if not paused :
248 | # Al continuar , capturar un nuevo frame de referencia y
seleccionar una nueva ROI
249 | if not capture_reference_frame () :
250 | break | # Salir si no se pudo capturar el frame de
referencia
251 | print (" Pausado " if paused else " Continuando con nueva referencia
")

252
253 | # Salir con la tecla ’q’
254 | if key & 0 xFF == ord (’q’) :
255 | break

256
257 | # Guardar el archivo Excel
258 | output_file = " a n a l i s i s _ d e f o r m a c i n 2 . xlsx "
259 | wb . save ( output_file )
260 | print ( f" Datos guardados en { output_file }")

261
262 | # Liberar la c m a r a principal , el VideoWriter y cerrar ventanas
263 | cap . release ()
264 | video_output . release ()

265
266 | # Liberar la segunda c m a r a y su VideoWriter
267 | cap2 . release ()
268 | video_output2 . release ()

269
270 cv2 . destroyAllWindows ()

271
272 | # Cierra el puerto serial
273 | puerto_serial . close ()

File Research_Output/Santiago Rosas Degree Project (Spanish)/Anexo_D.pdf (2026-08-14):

# Anexo D: Integración del Sistema, Software de Adquisición de Datos y Control

### Santiago Rosas Mogollón

### Marzo 2025

## 1. Descripción General de la Integración Hardware-Software

Este documento complementario detalla la arquitectura de firmware y control en Python uti-lizada para la sincronización del subsistema óptico y mecánico. El objetivo principal es desglosar de forma transparente el funcionamiento del firmware analógico de la celda de carga/sensor de tensión, el generador de pulsos del motor a través del microcontrolador Arduino, y el script maestro de control basado en Python, preservando las estructuras de flujo originales analizadas durante el proceso de desarrollo y depuración (debugging).

## 2. Software de Adquisición de Datos de Tensión

El primer módulo de control de bajo nivel se implementó sobre una plataforma Arduino con la finalidad de leer los cambios transductores analógicos proporcionales a la tensión mecánica ejercida en el sistema.

### 2.1. Procesamiento Digital de Señal y Ecuación de Conversión

El convertidor analógico-digital (ADC) de la placa opera con una resolución nativa de 10 bits, lo que mapea los voltajes de entrada entre 0 V y 5 V a un rango discreto de enteros [0, 1023]. La conversión e instrumentación matemática implementada en el firmware sigue la siguiente ecuación explícita:

Fuerza = valorLeido ×

5,0
1023,0
× 97,54 | (1)

Donde la constante 97,54 actúa como el factor de escala o ganancia de calibración lineal del sistema para transformar el voltaje medido directamente a unidades de fuerza o tensión. El retardo del bucle se fija en ∆t = 300 ms mediante la función delay(300), definiendo una tasa de muestreo aproximada de 3,33 Hz.

## 3. Software de Control del Motor

El segundo microcontrolador está dedicado de manera exclusiva a la modulación y generación de los pulsos digitales requeridos por el Driver Rtelligent para comandar el motor.

### 3.1. Modulación de Frecuencia por Software y Entrada Serial

Al arrancar el módulo, se parametriza una frecuencia nominal base de 200 Hz, traduciéndose a microsegundos mediante la relación:

periodo = 1, 000, 000
frecuencia | (2)

El bucle de control monitorea continuamente el buffer serial a 115200 bps. Al recibir una cadena de texto a través del bus, el programa discrimina entre dos rutas lógicas secuenciales:

Si la cadena es exactamente igual a la palabra clave "STOP", conmuta el pin digital a nivel bajo (LOW) para detener el movimiento.

De lo contrario, procesa la cadena transformándola a un tipo numérico entero (input.toInt()) y actualiza en tiempo real el valor del período de la onda cuadrada.

## 4. Software de Control Centralizado en Python

El programa maestro implementado en Python actúa como el núcleo de sincronización. Este integra la visión artificial por computadora (vía OpenCV), la adquisición de fuerza a través de puertos serie y la generación automática de la memoria de datos en formato Excel.

### 4.1. Configuración de ORB

En esta etapa de integración el computo de ORB se parametriza explícitamente con los siguientes coeficientes operativos para afinar la detección de keypoints en la Región de Interés (ROI):

nfeatures=500: Limita la extracción a un máximo de 500 puntos clave para resguardar la latencia de procesamiento.

scaleFactor=1.2 y nlevels=8: Estructura una pirámide de escala de 8 niveles con un factor de reducción del 20 % por nivel para otorgar tolerancia multiescala.

scoreType=cv2.ORB HARRIS SCORE: Utiliza el algoritmo clásico de Harris para rankear los puntos de interés en función de la matriz de covariancia de gradientes locales.

### 4.2. Flujo de Control Multi-Puerto (Serial) y Sincronización

El script realiza una apertura paralela de dos puertos de comunicación independientes sobre el sistema operativo: COM4 (dedicado a la escucha pasiva del flujo de lecturas de tensión de la celda) y COM3 (dedicado al envío activo de comandos de control de velocidad hacia el controlador del motor).

## Apéndice I: Código de Adquisición de Datos de Tensión (Arduino)

1 | // Definir el pin a n a l g i c o que se u s a r
2 | const int pinAnalogico = A0 ; | // Puedes usar A1 , A2 , etc .
3 | int valorLeido = 0; | // Variable para almacenar el valor de lectura
4 | float Fuerza = 0.0; | // Variable para almacenar el voltaje real

5
6 | void setup () {
7 | // Inicia la c o m u n i c a c i n serial para ver el resultado en el Monitor
Serial
8 | Serial . begin (115200) ;
9 | }

10
11 | void loop () {
12 | // Lee el valor del pin a n a l g i c o
13 | valorLeido = analogRead ( pinAnalogico ) ;

14
15 | // Convierte el valor l e d o a un voltaje real (0 a 5 V)
16 | Fuerza = valorLeido * (5.0 / 1023.0) *97.54; | // F r m u l a de
c o n v e r s i n

17
18 // Muestra el valor l e d o y el voltaje calculated en el Monitor Serial

19
20 | Serial . print (" Valor l e d o : ") ;
21 | Serial . print ( valorLeido ) ;
22 | Serial . print (" | Fuerza : ") ;
23 | Serial . println ( Fuerza ) ;

24
25 | // Espera un segundo antes de leer nuevamente
26 | delay (300) ;
27 | }

## Apéndice II: Código de Control del Motor (Arduino)

1 | // Definir el pin donde se g e n e r a r | el pulso
2 | const int pinPulso = 9; | // Pin 9 es v l i d o en Arduino Uno
3 | // Variable para almacenar la frecuencia deseada (en Hz)
4 | int frecuencia = 200; | // Frecuencia inicial

5
6 | // Variable para almacenar el p e r o d o del pulso (en microsegundos )
7 | unsigned long periodo ;

8
9 | void setup () {
10 | // Configurar el pin como salida
11 | pinMode ( pinPulso , OUTPUT ) ;
12 | digitalWrite ( pinPulso , LOW ) ;
13 | // Iniciar la c o m u n i c a c i n serial
14 | Serial . begin (115200) ;
15 | // Calcular el p e r o d o inicial
16 | periodo = 1000000 / frecuencia ; | // 1 segundo = 1 ,000 ,000
microsegundos

17 }

18
19 | void loop () {
20 | if ( Serial . available () > 0) {
21 | String input = Serial . readStringUntil (’\n’) ;

22
23 | if ( input == " STOP ") {
24 | // Detener completamente los pulsos
25 | digitalWrite ( pinPulso , LOW ) ;
26 | } else {
27 | // Procesar como frecuencia
28 | frecuencia = input . toInt () ;
29 | periodo = 1000000 / frecuencia ;
30 | }
31 | }

32
33 | if ( frecuencia > 0) { | // Solo generar pulsos si frecuencia > 0
34 | digitalWrite ( pinPulso , HIGH ) ;
35 | delayMicroseconds ( periodo / 2) ;
36 | digitalWrite ( pinPulso , LOW ) ;
37 | delayMicroseconds ( periodo / 2) ;
38 | } else { digitalWrite ( pinPulso , LOW ) ;}
39 | }

## Apéndice III: Código de Control Principal (Python)

1 | import cv2
2 | import numpy as np
3 | import time
4 | from openpyxl import Workbook
5 | from datetime import datetime
6 | import serial

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

14
15 | MOTOR_FREQUENCY = 200 | # Frecuencia inicial del motor en Hz

16
17 | # Inicializar ORB
18 | orb = cv2 . ORB_create ( nfeatures =500 ,
19 | scaleFactor =1.2 ,
20 | nlevels =8 ,
21 | edgeThreshold =31 ,
22 | firstLevel =0 ,
23 | WTA_K =2 ,
24 | scoreType = cv2 . ORB_HARRIS_SCORE ,
25 | patchSize =31 ,
26 | fastThreshold =20)

27
28 | # Inicializar la c m a r a principal
29 | cap = cv2 . VideoCapture (1) | # Usar la c m a r a predeterminada ( c m a r a web
)

30
31 | # Inicializar la segunda c m a r a
32 | cap2 = cv2 . VideoCapture (0) | # Usar la segunda c m a r a

33
34 | # Verificar si las c m a r a s se abrieron correctamente
35 | if not cap . isOpened () :
36 | print (" Error : No se pudo abrir la c m a r a principal .")
37 | exit ()

38
39 | if not cap2 . isOpened () :
40 | print (" Error : No se pudo abrir la segunda c m a r a .")
41 | exit ()

42
43 | # Configurador de r e s o l u c i n a 1080 p para ambas camaras
44 | cap .set ( cv2 . CAP_PROP_FRAME_WIDTH , RESOLUCION [0])
45 | cap .set ( cv2 . CAP_PROP_FRAME_HEIGHT , RESOLUCION [1])

46
47 | cap2 .set ( cv2 . CAP_PROP_FRAME_WIDTH , RESOLUCION [0])
48 | cap2 .set ( cv2 . CAP_PROP_FRAME_HEIGHT , RESOLUCION [1])

49
50 | # Obtener la r e s o l u c i n del frame de la c m a r a principal
51 | frame_width = int ( cap . get ( cv2 . CAP_PROP_FRAME_WIDTH ) )
52 | frame_height = int ( cap . get ( cv2 . CAP_PROP_FRAME_HEIGHT ) )
53 | fps = int ( cap . get ( cv2 . CAP_PROP_FPS ) )

54
55 # Obtener la r e s o l u c i n del frame de la segunda c m a r a

56 | frame_width2 = int ( cap2 . get ( cv2 . CAP_PROP_FRAME_WIDTH ) )
57 | frame_height2 = int ( cap2 . get ( cv2 . CAP_PROP_FRAME_HEIGHT ) )
58 | fps2 = int ( cap2 . get ( cv2 . CAP_PROP_FPS ) )

59
60 | # Inicializar VideoWriter para guardar el video de la c m a r a principal
61 | video_output = cv2 . VideoWriter (’ salida_video_macro .mp4 ’, cv2 .
VideoWriter_fourcc (* ’mp4v ’) , fps , RESOLUCION )
62 | video_output .set ( cv2 . VIDEOWRITER_PROP_QUALITY , CALIDAD )
63 | # Inicializar VideoWriter para guardar el video de la segunda c m a r a
64 | video_output2 = cv2 . VideoWriter (’ salida_video_micro .mp4 ’, cv2 .
VideoWriter_fourcc (* ’mp4v ’) , fps2 , RESOLUCION )
65 video_output2 .set ( cv2 . VIDEOWRITER_PROP_QUALITY , CALIDAD )

66
67 | # Variables para almacenar el frame de referencia
68 | reference_frame = None
69 | reference_keypoints = None
70 | reference_descriptors = None
71 | roi = None | # Variable para almacenar la ROI

72
73 | # Variable para controlar el tiempo
74 | last_time = time . time ()
75 | interval = 0.3 | # Intervalo de 0.3 segundo

76
77 | # Umbral para ignorar desplazamientos p e q u e o s (en p x e l e s )
78 | displacement_threshold = 1 | # Ignorar desplazamientos menores a 1 p x e l

79
80 | # Crear un archivo Excel para guardar los datos
81 | wb = Workbook ()
82 | ws = wb . active
83 | ws . title = " D e f o r m a c i n "
84 | ws . append ([" Timestamp ", " Desplazamiento ( p x e l e s )", " Valor l e d o ", "
Newtons "]) | # Encabezados

85
86 | # Variable para controlar la pausa
87 | paused = False
88 | puerto_serial = serial . Serial (’COM4 ’, 115200 , timeout =1)
89 | puerto_serial2 = serial . Serial (’COM3 ’, 115200 , timeout =1)

90
91 | # F u n c i n para controlar el motor
92 | def control_motor ( frequency = None ) :
93 | if frequency is not None :
94 | puerto_serial2 . write ( f"{ frequency }\n". encode () )
95 | else :
96 | puerto_serial2 . write (" STOP \n". encode () )

97
98 | # F u n c i n para mantener el frame de referencia y seleccionar la ROI
99 | def capture_reference_frame () :
100 | global reference_frame , reference_keypoints , reference_descriptors ,
roi
101 | ret , frame = cap . read ()
102 | if not ret :
103 | print (" Error : No se pudo capturar el frame de referencia .")
104 | return False

105
106 | # Mostrar el frame y permitir al usuario seleccionar la ROI
107 | roi = cv2 . selectROI (" Selecciona la ROI ", frame , fromCenter = False ,
showCrosshair = True )
108 | cv2 . destroyWindow (" Selecciona la ROI ")

109
110 | # Recortar el frame de referencia s e g n la ROI
111 | reference_frame = cv2 . cvtColor ( frame , cv2 . COLOR_BGR2GRAY )
112 | reference_frame = reference_frame [int ( roi [1]) :int ( roi [1] + roi [3]) ,
| int( roi [0]) :int( roi [0] + roi [2]) ]

113
114 | # Detectar puntos c a r a c t e r s t i c o s y descriptores en la ROI
115 | reference_keypoints , reference_descriptors = orb . detectAndCompute (
| reference_frame , None )
116 | if reference_descriptors is None :
117 | print (" Error : No se pudieron calcular los descriptores de
| referencia .")
118 | return False
119 | print (" Frame de referencia capturado y ROI seleccionada .")
120 | return True
121 | control_motor ( MOTOR_FREQUENCY )

122
123 | # Capturar el frame de referencia y seleccionar la ROI inicial
124 | if not capture_reference_frame () :
125 | cap . release ()
126 | cap2 . release ()
127 | cv2 . destroyAllWindows ()
128 | exit ()

129
130 | last_time = time . time ()
131 | interval = 0.3
132 | last_valid_displacement = 0.0
133 | newtons = 0.0
134 | valor_leido = 0.0

135
136 | while True :
137 | ret , frame = cap . read ()
138 | if not ret :
139 | print (" Error : No se pudo capturar el frame de la c m a r a
| principal .")
140 | break
141 | frame_display = cv2 . resize ( frame , ( DISPLAY_WIDTH , DISPLAY_HEIGHT ) )

142
143 | ret2 , frame2 = cap2 . read ()
144 | if not ret2 :
145 | print (" Error : No se pudo capturar el frame de la segunda c m a r a
| .")
146 | break
147 | frame2_display = cv2 . resize ( frame2 , ( DISPLAY_WIDTH , DISPLAY_HEIGHT ) )

148
149 | frame_with_roi = frame . copy ()
150 | if roi is not None :
151 | cv2 . rectangle ( frame_with_roi , (int ( roi [0]) , int ( roi [1]) ) , (int (
| roi [0] + roi [2]) , int( roi [1] + roi [3]) ) , (0 , 255 , 0) , 2)

152
153 | if paused :
154 | cv2 . putText ( frame_with_roi , " PAUSADO ", (10 , 50) , cv2 .
| FONT_HERSHEY_SIMPLEX , 1 , (0 , 0 , 255) , 2 , cv2 . LINE_AA )

155
156 | cv2 . imshow (’Camera meso ’, frame_with_roi )

157
158 | if paused :
159 | frame2_paused = frame2 . copy ()

160 | cv2 . putText ( frame2_paused , " PAUSADO ", (10 , 50) , cv2 .
| FONT_HERSHEY_SIMPLEX , 1 , (0 , 0 , 255) , 2 , cv2 . LINE_AA )
161 | cv2 . imshow (’Camera micro ’, frame2_paused )
162 | else :
163 | cv2 . imshow (’Camera micro ’, frame2 )

164
165 | if not paused :
166 | video_output . write ( frame )
167 | video_output2 . write ( frame2 )

168
169 | current_time = time . time ()

170
171 | if not paused and current_time - last_time >= interval :
172 | gray = cv2 . cvtColor ( frame , cv2 . COLOR_BGR2GRAY )
173 | gray_roi = gray [int ( roi [1]) :int ( roi [1] + roi [3]) , int ( roi [0]) :
| int( roi [0] + roi [2]) ]

174
175 | keypoints , descriptors = orb . detectAndCompute ( gray_roi , None )

176
177 | if descriptors is not None and reference_descriptors is not None
:
178 | bf = cv2 . BFMatcher ( cv2 . NORM_HAMMING , crossCheck = True )
179 | matches = bf . match ( reference_descriptors , descriptors )

180
181 | average_displacement = 0.0
182 | if len ( matches ) > 0:
183 | matches = sorted ( matches , key = lambda x : x . distance )

184
185 | displacements = []
186 | for match in matches :
187 | pt1 = reference_keypoints [ match . queryIdx ]. pt
188 | pt2 = keypoints [ match . trainIdx ]. pt
189 | dx = pt2 [0] - pt1 [0]
190 | dy = pt2 [1] - pt1 [1]
191 | displacement = np . sqrt ( dx **2 + dy **2)
192 | displacements . append ( displacement )

193
194 | average_displacement = np . mean ( displacements )

195
196 | if average_displacement > displacement_threshold :
197 | print ( f" Desplazamiento promedio : {
| average_displacement :.2 f} p x e l e s ")
198 | last_valid_displacement = average_displacement
199 | else :
200 | print (" Desplazamiento despreciable ( ruido )")
201 | average_displacement = last_valid_displacement
202 | else :
203 | print ("No se encontraron matches . Usando el | ltimo
| desplazamiento v l i d o .")
204 | average_displacement = last_valid_displacement

205
206 | if len ( matches ) > 0:
207 | ref_resized = cv2 . resize ( reference_frame , ( DISPLAY_WIDTH
| // 2 , DISPLAY_HEIGHT // 2) )
208 | current_resized = cv2 . resize ( gray_roi , ( DISPLAY_WIDTH //
| 2 , DISPLAY_HEIGHT // 2) )
209 | output_frame = cv2 . drawMatches ( ref_resized ,
reference_keypoints , current_resized , keypoints , matches [:50] , None ,

flags =2)
210 | output_frame = cv2 . resize ( output_frame , ( DISPLAY_WIDTH ,
DISPLAY_HEIGHT // 2) )
211 | cv2 . imshow (’Matches ’, output_frame )
212 | else :
213 | print ("No se pudieron calcular los descriptores . Usando el
ltimo | desplazamiento v l i d o .")
214 | average_displacement = last_valid_displacement

215
216 | linea = puerto_serial . readline () . decode (’utf -8 ’) . strip ()
217 | if linea :
218 | partes = linea . split ()
219 | if len ( partes ) >= 5:
220 | valor_leido = float ( partes [2])
221 | newtons = float ( partes [4])
222 | print ( f" Fuerza :{ newtons :.2 f}")
223 | timestamp = datetime . now () . strftime (" %Y- %m- %d %H: %M: %S. %
f")
224 | ws . append ([ timestamp , average_displacement , valor_leido ,
newtons ])

225
226 | last_time = current_time

227
228 | key = cv2 . waitKey (1)
229 | if key & 0 xFF == ord (’p’) :
230 | control_motor ( None )
231 | paused = not paused
232 | if not paused :
233 | if not capture_reference_frame () :
234 | break
235 | print (" Pausado " if paused else " Continuando con nueva referencia
")

236
237 | if key & 0 xFF == ord (’q’) :
238 | control_motor ( None )
239 | break

240
241 | output_file = " a n a l i s i s _ d e f o r m a c i n . xlsx "
242 | wb . save ( output_file )
243 | print ( f" Datos guardados en { output_file }")

244
245 | cap . release ()
246 | video_output . release ()
247 | cap2 . release ()
248 | video_output2 . write ( frame2 )
249 | video_output2 . release ()
250 | cv2 . destroyAllWindows ()

251
252 | puerto_serial . close ()
253 | puerto_serial2 . close ()

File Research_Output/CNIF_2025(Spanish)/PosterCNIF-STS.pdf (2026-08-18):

Ensayos de Tracción con Visión por Computador.

## Análisis sin Contacto de Deformaciones y Mecanismos de Falla en Materiales Heterogéneos

# Resumen

En esta contribución se presentó un sistema de bajo costo para ensayos de tracción, compuesto por un desarrollo de hardware abierto y un conjunto de algoritmos de código abierto de visión por computadora para la evaluación de tensión-deformación sin contacto.
Se propuso un instructivo de tallado para su construcción y una serie de experimentos de evaluación de rendimiento. Se apartaron adaptaciones que permiten pruebas tanto de micro tensión como tensiones con cargas de hasta 50kgf, adicional a la caracterización de materiales con micro heterogeneidad estructural, y aquellos de referencia para comparación interlaboratorios.

# Materiales y Métodos

## Entornos del Sistema

El sistema general fue diseñado para integrar tres entornos que, al acoplarse y sincronizarse, forman un conjunto unificado capaz de realizar análisis de las deformaciones y de los mecanismos de falla: • Hardware de generación y control de tensión uniaxial. • Sistema de adquisición de imágenes. • Control general mediante computadora.

Figura 1: Diferentes entornos del sistema en un ensayo sobre una muestra de cobre.

Resultados y análisis | Conclusiones • El prototipo es una alternativa innovadora para el análisis de materiales heterogéneos. Los resultados son prometedores, aunque se requiere optimización para ampliar su aplicación en distintos contextos de estudio. Demuestra un gran potencial para analizar deformaciones y mecanismos de falla. • El enfoque del proyecto en el movimiento de open hardware y open software ha demostrado ser un pilar esencial en el desarrollo colectivo de la ciencia. Gracias a esta filosofía se facilitó el acceso a herramientas, conocimientos y tecnologías que, de otro modo, habrían sido limitadas o inaccesibles. Agradecimientos Agradecemos todo el apoyo proporcionado por la Universidad Nacional de Colombia. También expresamos nuestro agradecimiento a Edison Ferney Abril Romero y a Jhon Jairo Fajardo Toledo por su invaluable ayuda en el desarrollo del sistema mecánico; y a José Alfredo Gómez Mateus por su orientación en la comprensión fundamental de los protocolos DIC (Correlación de Imágenes Digitales). Este proyecto forma parte del semillero con código Hermes 60225. Referencias Para conocer todas las referencias utilizadas en este proyecto, escanee el código QR

Autores: Serena Triviño Sáenz – strivinos@unal.edu.co Santiago Rosas Mogollón - srosasm@unal.edu.co Carlos Mario Garzón Ospina - cmgarzono@unal.edu.co Grupo de Microscopía Electrónica – Departamento de Física

Figura 2: Muestras para ensayos (de izq. A der.) cobre con recubrimiento de acero por magnetrón, plataforma de colágeno bovino, PLA, biopolímero a base Maizena.

A continuación, las Figuras 5, 4 y 3 muestran tanto la operación de la interfaz como los resultados de las deformaciones y los mecanismos de fallo.

Figura 4: Mecanismo de falla en muestra de cobre con recubrimiento de acero inoxidable.

Figura 3: Ensayo de tensión deformación en plataformas de colágeno bovino.

Figura 5: Curvas de Tensión Elongación.

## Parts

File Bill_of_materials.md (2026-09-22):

| Component | Number | Cost per unit - currency | Total cost - currency | Source of materials | Material type |
|:--|:--|:--|:--|:--|:--|
| 23.2 mm C-Mount Microscope Camera Adapter | 1 | 11.10 USD | 11.10 USD | https://n9.cl/liqh7j | Microscope Eyepiece Adapter |
| 3D support for the micro-scale camera | 1 | 5.87 USD | 5.87 USD | [View STL design](/./Design_files/3D_Models/Support.stl) | 3D Printed in PLA |
| 3 W Coaxial Point LED Spot Light | 1 | 42.99 USD | 42.99 USD | https://n9.cl/lxyam | Coaxial Light 8 mm |
| 480 W, 48 V, 10 A Power Supply | 1 | 39.99 USD | 39.99 USD | https://n9.cl/ob4bt | Drok-200570 |
| Actuator base | 1 | 7.80 USD | 7.80 USD | [View DWG design](/./Design_files/3D_Models/Actuator_base.dwg) | Bronze (machined) |
| Adjustable Zoom Barlow Monocular | 1 | 91.93 USD | 91.93 USD | https://n9.cl/ynerq | TV150 W075 |
| Adjustable Zoom Barlow Monocular | 1 | 80.03 USD | 80.03 USD | https://n9.cl/ynerq | TV050 W050 |
| Arduino Nano | 1 | 4.54 USD | 4.54 USD | https://n9.cl/oshd52 | Arduino Nano |
| Arduino Uno | 1 | 8.39 USD | 8.39 USD | https://n9.cl/uhr78 | Arduino Uno R3 |
| Camera Lens Cleaning Kit | 1 | 19.99 USD | 19.99 USD | https://n9.cl/rqw6h | Zacro |
| Ceramic Capacitors | 2 | 0.12 USD | 0.24 USD | Electronics Stores | Ceramic |
| Clamping Plug | 1 | 0.50 USD | 0.50 USD | [View STL design](/./Design_files/3D_Models/Clamping%20plug.stl) | 3D Printed in PLA |
| Digital Industrial Microscope Camera | 2 | 100.98 USD | 201.96 USD | https://n9.cl/54ddm | Maant XJ-1 2 |
| Electrolytic Capacitors | 2 | 0.12 USD | 0.24 USD | Electronics Stores | Composite |
| Fine Adjustable Focusing Bracket Holder | 1 | 98.00 USD | 98.00 USD | https://n9.cl/hs8yf | 76mm - 25mm |
| Half Reflection–Half Transmission Lens Adapter | 1 | 55.55 USD | 55.55 USD | https://n9.cl/ozm6x | RMS20.23 |
| Hexagonal allen screws M5×15 mm | 6 | 0.15 USD | 0.90 USD | Screws Stores | Steel |
| Hexagonal button head screws M6×16 mm | 4 | 0.15 USD | 0.60 USD | Screws Stores | Steel |
| Hexagonal button head screws M6×20 mm | 2 | 0.17 USD | 0.34 USD | Screws Stores | Steel |
| Hexagonal button head screws M6×25 mm | 4 | 0.20 USD | 0.80 USD | Screws Stores | Steel |
| Hexagonal countersunk screws M5×16 mm | 4 | 0.05 USD | 0.20 USD | Screws Stores | Steel |
| Hexagonal countersunk screws M5×20 mm | 2 | 0.12 USD | 0.24 USD | Screws Stores | Steel |
| Hexagonal countersunk screws M5×70 mm | 2 | 0.20 USD | 0.40 USD | Screws Stores | Steel |
| Hexagonal set screws M6×16 mm | 6 | 0.05 USD | 0.30 USD | Screws Stores | Steel |
| Hexagonal nuts M6 | 3 | 0.03 USD | 0.09 USD | Screws Stores | Steel |
| Keyboard and mouse | 1 | 35.99 USD | 35.99 USD | https://n9.cl/63x0c | Logitech MK295 |
| Knurled screw M6×25 mm | 1 | 0.75 USD | 0.75 USD | Screws Stores | Steel |
| Linear Motion Ball-Screw Rail Actuator | 1 | 169.99 USD | 169.99 USD | https://n9.cl/dx8bn | Heechoo HRC60-100B2 |
| Load Cell Amplifier Transmitter | 1 | 8.36 USD | 8.36 USD | https://n9.cl/wj5ek | WXD-D70 |
| Load Cell Signal Transmitter | 2 | 22.09 USD | 44.18 USD | https://n9.cl/h2mejt | Shitailinge |
| Long WD Infinity Plan Objective Lens 5× | 1 | 42.97 USD | 42.97 USD | https://n9.cl/syld4q | JLLSMCMGGX |
| Microscope Polarized LED Ring Light | 2 | 23.96 USD | 47.92 USD | https://n9.cl/23sygc | Wozniak ILFixes iL37 |
| Microscope Reticle Calibrating Slide Ruler | 1 | 9.11 USD | 9.11 USD | https://n9.cl/o5htf2 | Optical Glass (0.01 mm div.) |
| Mini PC | 1 | 319.00 USD | 319.00 USD | https://n9.cl/rgvvx | BOSGAME B-95, Intel N95 12th Gen |
| Miniature S-type Load Cell 1 kgf | 1 | 49.60 USD | 49.60 USD | https://n9.cl/4bg0g | DYLY-106 |
| Miniature S-type Load Cell 50 kgf | 1 | 65.00 USD | 65.00 USD | https://n9.cl/0rp10 | DYLY-106 |
| NEMA 23 Closed-Loop Servo-Stepper Motor + Driver | 1 | 99.99 USD | 99.99 USD | https://n9.cl/03rna | Rtelligent 57A3ED + T60 |
| Phillips flat head screws M4×5 mm | 2 | 0.10 USD | 0.10 USD | Screws Stores | Steel |
| Positioning plate on the actuator | 1 | 4.40 USD | 4.40 USD | [View DWG design](/./Design_files/3D_Models/Positioning_plate.dwg) | Steel (machined) |
| Push-Pull Tester Jaw Clamp | 2 | 18.89 USD | 37.78 USD | https://n9.cl/cyou64 | SJJ-01 |
| Resistors | 1 | 0.03 USD | 0.03 USD | Electronics Stores | Composite |
| Sample aligner | 1 | 2.45 USD | 2.45 USD | [View DWG design](/./Design_files/3D_Models/Sample_aligner.dwg) | Bronze and steel (machined) |
| Slotted pan head screws M6×20 mm | 2 | 0.25 USD | 0.50 USD | Screws Stores | Steel |
| Slotted pan head screws M6×30 mm | 2 | 0.25 USD | 0.50 USD | Screws Stores | Nylon |
| Support for positioner and table attachment | 1 | 10.61 USD | 10.61 USD | [View DWG design](/./Design_files/3D_Models/Support_Attachment.dwg) | Bronze, steel, and aluminium (machined) |
| Transverse axis | 1 | 6.12 USD | 6.12 USD | [View DWG design](/./Design_files/3D_Modelsd/Transverse_axis.dwg) | Steel (machined) |
| Tripod | 1 | 52.30 USD | 52.30 USD | https://n9.cl/31szeq | Weifeng WT-3560 |
| USB 3.2 to USB-C Cable | 1 | 18.99 USD | 18.99 USD | https://n9.cl/kkwi2 | Aoybevty |
| USB 3.2 to USB-C Female Adapter | 1 | 9.99 USD | 9.99 USD | https://n9.cl/477rm | ANDTOBO |
| **Total** | | | **1,699.63 USD** | | |
<!--| Miniature S-type Load Cell 5 kgf | 1 | 68.00 USD | 68.00 USD | https://n9.cl/zc0ce | DYLY-106 | -->

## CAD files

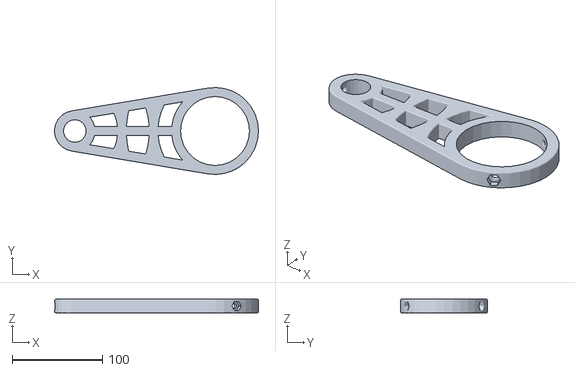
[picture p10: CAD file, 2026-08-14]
Design_Files/3D_Models/Camera_Support.stl
225.9 x 96.3 x 15.0

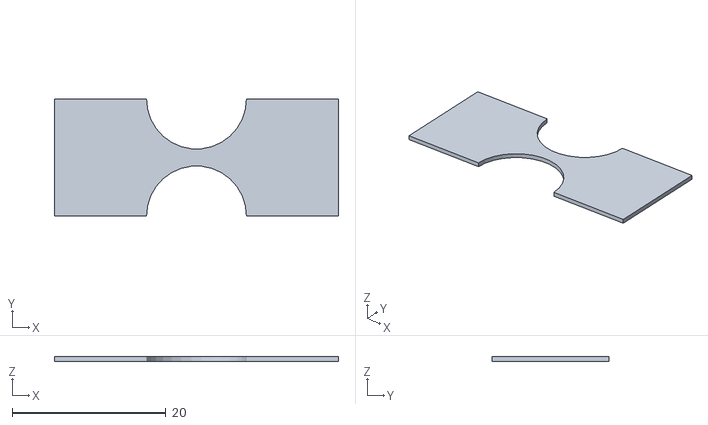
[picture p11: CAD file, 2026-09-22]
Design_Files/Sample_Standars/DB-PFM1.stl
37.0 x 15.2 x 0.6

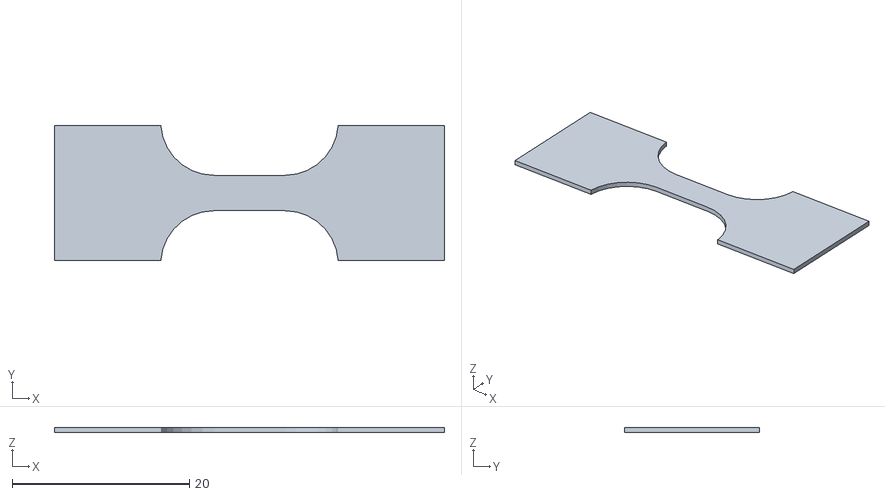
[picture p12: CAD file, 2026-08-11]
Design_Files/Sample_Standars/DB-PD1.stl
44.0 x 15.2 x 0.6

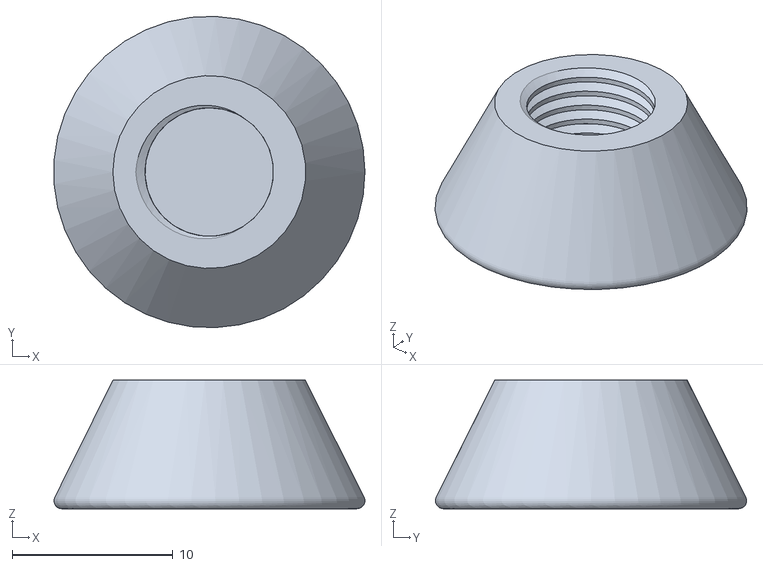
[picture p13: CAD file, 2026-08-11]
Design_Files/3D_Models/Clamping plug.stl
19.4 x 19.4 x 8.00

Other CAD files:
Complements/LC_Characterization_Assambly.dwg
Design_Files/3D_Models/Just_Barlow_3D_Model.dwg
Design_Files/Sample_Standars/DB-PFM1_Dim.dwg
Design_Files/3D_Models/Micro-Barlow_3D_Model.dwg
Design_Files/Sample_Standars/DB-PD1_Dim.dwg
Design_Files/3D_Models/Sample_aligner.dwg
Design_Files/3D_Models/Camera_micro_Ebarlow.dwg
Design_Files/3D_Models/Actuator_base.dwg
Design_Files/3D_Models/Positioning_plate.dwg
Design_Files/3D_Models/Transverse_axis.dwg
Design_Files/3D_Models/Support_Attachment.dwg
Design_Files/3D_Models/Fine Adjustable Focusing.dwg
Design_Files/3D_Models/Camera_macro_Barlow.dwg
Design_Files/3D_Models/Camera_micro_E5X.dwg
Design_Files/3D_Models/Clamping plug.dwg
Design_Files/Sample_Standars/DB-PD1.dwg
Design_Files/Sample_Standars/DB-PFM1.dwg

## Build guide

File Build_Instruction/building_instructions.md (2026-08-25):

# Building Instructions

## Introduction

Ditogachi is an open-hardware platform designed for micrometric deformation measurements during uniaxial tensile testing. The system combines mechanical loading, optical imaging, electronic instrumentation, and computer vision algorithms to enable simultaneous force and deformation measurements.

The hardware architecture can be divided into four main subsystems:

1. **Tensile loading system**, responsible for generating the mechanical load applied to the specimen.
2. **Microscopic imaging system**, responsible for acquiring high-magnification images for deformation measurements.
3. **Electronic instrumentation system**, responsible for motor control, force acquisition, and synchronization.
4. **Macroscopic imaging system**, consisting of an external camera mounted on a tripod when mesoscopic observations are required.

The assembly videos provided in this section cover the fabrication and assembly of the two principal mechanical subsystems: the tensile loading hardware and the microscopic imaging support structure.

Additional information regarding electronics, illumination, software, and operation can be found in the corresponding sections of this repository.

---

## System Architecture

The complete system is composed of:

- Tensile loading module.
- Microscope support and positioning module.
- Load-cell-based force measurement system.
- Motor control electronics.
- Illumination system.
- Optional macroscopic camera mounted on an external tripod.
- Computer vision and data acquisition software.

---

## 1. Optical System Support and Positioning Module

This module provides mechanical support for the microscope camera used during deformation measurements. The structure ensures stability during testing while allowing positioning and fine adjustment of the optical system relative to the specimen.

The microscope support is designed to minimize vibrations and facilitate precise focusing and alignment during image acquisition.

### Assembly Video

https://youtu.be/Ijc06AQWEIM

<sub>
<strong>Credits:</strong><br>
Assembly and Editing: Santiago Rosas Mogollón<br>
Filming and Review: Serena Triviño Sáenz
</sub>

### Description

This video presents the complete assembly procedure for the microscope support structure, including the installation of positioning mechanisms and adjustment components required for stable image acquisition.

### Notes

- This module supports the **microscopic imaging system only**.
- The macroscopic camera used in some experiments is not part of this assembly and can be mounted independently using a conventional laboratory tripod.  

---

## 2. Tensile Loading Module

This module constitutes the mechanical core of Ditogachi. It generates the tensile load applied to the specimen and provides the structural framework required for uniaxial testing.

The system incorporates a motor-driven actuation mechanism, specimen grips, and a load cell capable of measuring forces during testing.

### Assembly Video

https://youtu.be/UyuWO1eD-a8

<sub>
<strong>Credits:</strong><br>
Assembly and Editing: Santiago Rosas Mogollón<br>
Filming and Review: Serena Triviño Sáenz
</sub>

### Description

This video presents the complete assembly procedure for the tensile loading hardware, including structural elements, actuation components, specimen grips, and force-measurement integration.

---

## Electronics and Wiring

The assembly of the electronic instrumentation is documented separately through wiring diagrams and circuit documentation included in this repository.

These documents describe:

- Motor control connections.
- Load cell instrumentation.
- Arduino-based control hardware.
- Power distribution.
- Communication interfaces.

Users should review the electronic documentation before operating the system.

---

## License

Build instruction videos and accompanying documentation are distributed under the Creative Commons Attribution 4.0 International License (CC BY 4.0).

https://creativecommons.org/licenses/by/4.0/

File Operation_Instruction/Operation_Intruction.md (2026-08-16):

# Operation Instructions

This section describes the standard operating procedure used to perform quasi-static tensile experiments and synchronized image-based deformation measurements using the **Potrómetro**, our proposed Open-Hardware development.

## Initial Conditions and System Preparation

All experiments were performed at room temperature under quasi-static loading conditions. Prior to each test, the system was inspected to ensure correct electrical connections (for detailed information on the electronic assembly, see the *Building Instructions* file), mechanical alignment, and proper communication between hardware and software components.

Before performing the test, the sample was marked with a pattern of dots aligned with its geometric center. The sample was then mounted between the mechanical grips and aligned with the vertical loading axis.

The macro camera was positioned at an inclination angle between 10° and 20° relative to the sample surface to ensure an adequate field of view, while the micro camera was positioned perpendicular to the sample. Both cameras were connected to the acquisition computer using USB 3.0 connections. Camera focus and illumination were adjusted manually before starting each test.

## Hardware Configuration

The linear actuation system consisted of a lead screw with a pitch of 5 mm/rev, driven by a closed-loop NEMA 23 servo/stepper motor (Rtelligent 57AM30ED or equivalent), controlled through a T60 driver configured at 40,000 microsteps. Under this configuration, a pulse frequency of 300 Hz resulted in a displacement rate of approximately 0.05 mm/s, ensuring quasi-static loading conditions. The electronic components mentioned are specified in the *Building Instructions* and *Bill of Materials*.

Force measurements were acquired using a load cell instrumented with strain gauges and connected to an Arduino Nano microcontroller. Motor control signals were generated by an Arduino Uno, which output a pulse-width modulated (PWM) signal with configurable frequency. Both microcontrollers communicated with the acquisition computer through serial communication at a baud rate of 115200.

## Operational Sequence

1. Mount and align the sample between the grips (see Fig. 3).
2. Focus and align the cameras according to the macro and micro configurations using the proprietary software provided by the camera manufacturer. If a different camera is used, this procedure can be performed using the computer’s camera application.
3. Launch the Python acquisition software and establish serial communication with both Arduino boards.
4. Activate the motor by sending a pulse signal at the predefined frequency.
5. Manually select the region of interest (ROI) corresponding to the sample area to be tracked (see Fig. 4).
6. Acquire force data and image frames synchronously during the loading process.
7. If pausing the experiment is required, press the `p` key to temporarily halt data acquisition. Press the same key again to resume the experiment.
8. Terminate the experiment manually by pressing the `q` key once the desired deformation level or failure condition has been reached.

## Data Acquisition and Synchronization

Force measurements were acquired through the Arduino Nano by reading amplified voltage signals from the load cell and converting them into force values using previously established calibration parameters. The Python software requested force measurements on demand and stored them synchronously with image acquisition.

Image acquisition was performed using OpenCV. Two acquisition modes were implemented:

1. **Image capture for post-processing analysis**
2. **Real-time deformation analysis**

In both modes, image frames from the macro and micro cameras were captured within a single acquisition loop to avoid data desynchronization and frame-rate instability.

In post-processing mode, each captured frame was associated with a corresponding force measurement. In real-time mode, characteristic points were detected using the ORB (*Oriented FAST and Rotated BRIEF*) algorithm, and frame-to-frame feature matching was performed. Mean displacements along the x and y axes, as well as a global displacement metric, were computed using NumPy and stored together with force data.

## Calibration Procedure

Prior to experimental testing, the load cell was calibrated using known reference loads to establish the voltage-to-force conversion relationship.

Camera-based displacement measurements relied on the known optical parameters of the macro and micro imaging systems, including field of view and magnification.

Calibration procedures were repeated whenever hardware components were reassembled or camera configurations were modified.

## Output Data and Post-Processing

Force data and associated displacement measurements were stored in spreadsheet format using OpenPyXL. Image frames from both cameras were saved to disk during acquisition.

After completion of the experiment, video files were generated from the recorded frames using FFmpeg via terminal commands.

This acquisition strategy was adopted to ensure temporal consistency between force and image data and to avoid issues such as irregular frame rates or data loss observed during preliminary testing.

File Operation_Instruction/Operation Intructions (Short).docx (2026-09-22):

Operation Instructions

All experiments were performed at room temperature, under quasi-static loading conditions. Prior to each test the system was inspected to ensure correct electrical connections, mechanical alignment and proper communication between hardware and software components. Also, the load cell was calibrated using known reference loads to establish the voltage-to-force conversion.

Before performing the test, the sample was marked with a pattern of dots aligned and parallels to its geometric center, as shown in Fig. 1. The macro camera was positioned at an angle between 10° and 20° relative to the sample surface’s normal vector, while the micro camera was positioned perpendicular to the sample to ensure an adequate field of view. Both cameras were connected to the acquisition computer using USB 3.0 connections. Camera focus and illumination were adjusted manually before starting each test.

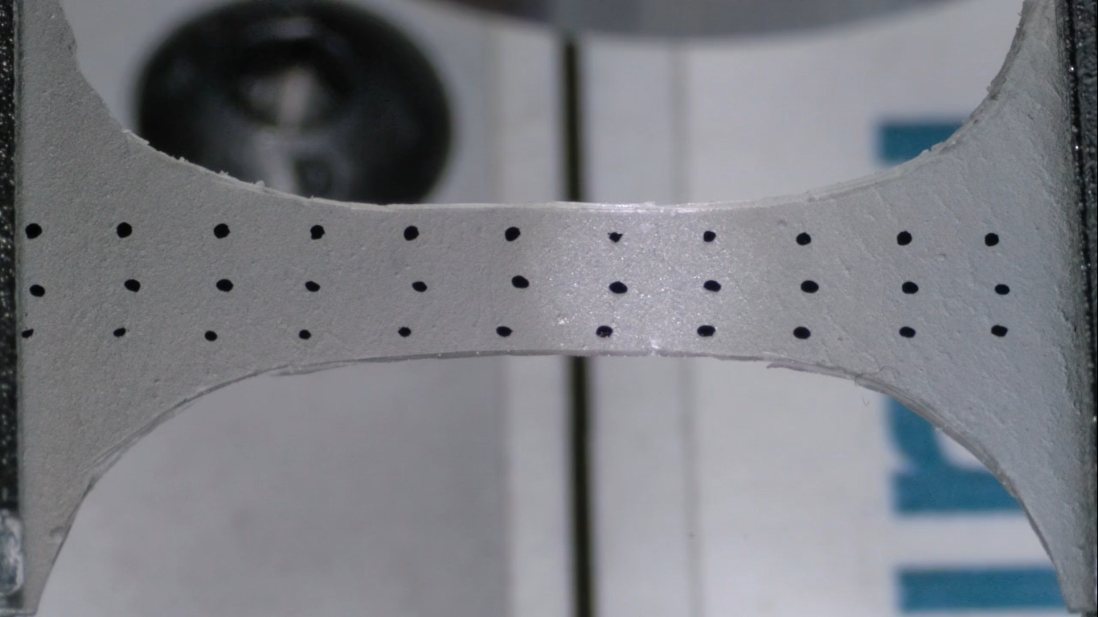
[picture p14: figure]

Fig. 1. Dot pattern on Cornstarch Biopolymer.

The linear actuation system consisted of a lead screw with a pitch of 5 mm/rev, driven by a closed-loop NEMA 23 servo/stepper motor controlled through a T60 driver configured at 40000 microsteps. Under this configuration, a pulse frequency of 200 Hz resulted in a displacement rate of approximately 0.025 mm/s, ensuring quasi-static loading conditions.

Force measurements were acquired using a load cell and connected to an Arduino Nano microcontroller. Motor control signals were generated by an Arduino Uno, which outputs a pulse wide modulated signal with configurable frequency through PWM pins. Both microcontrollers communicated with the acquisition computer through serial communication at a baud rate of 115200.

Operational Sequence

1. The sample was mounted and aligned between the grips.
2. The cameras were focused and aligned according to the macro and micro configurations, using the proprietary software provided by the camera manufacturer.
3. The Python software was launched, establishing serial communication with both Arduino boards. The region of interest (ROI) corresponding to the sample area to be tracked was manually selected.
4. Force data and image frames were acquired synchronously during the loading process. If pausing the experiment is required, the “p” key is pressed to temporarily halt data acquisition. The experiment is resumed by pressing the same key. The experiment is terminated manually by pressing the “q” key once the desired deformation level or failure condition is reached.

Image acquisition was performed using OpenCV. In post-processing mode, each captured frame was associated with a corresponding force measurement. In real-time mode, characteristic points were detected using the ORB algorithm, and frame-to-frame feature matching was performed. Force data and associated displacement measurements were stored in spreadsheet format using OpenPyXL. Image frames from both cameras were saved to disk during acquisition. After completion of the experiment, video files were generated from the recorded frames using FFmpeg via terminal commands detailed in the python program printout.

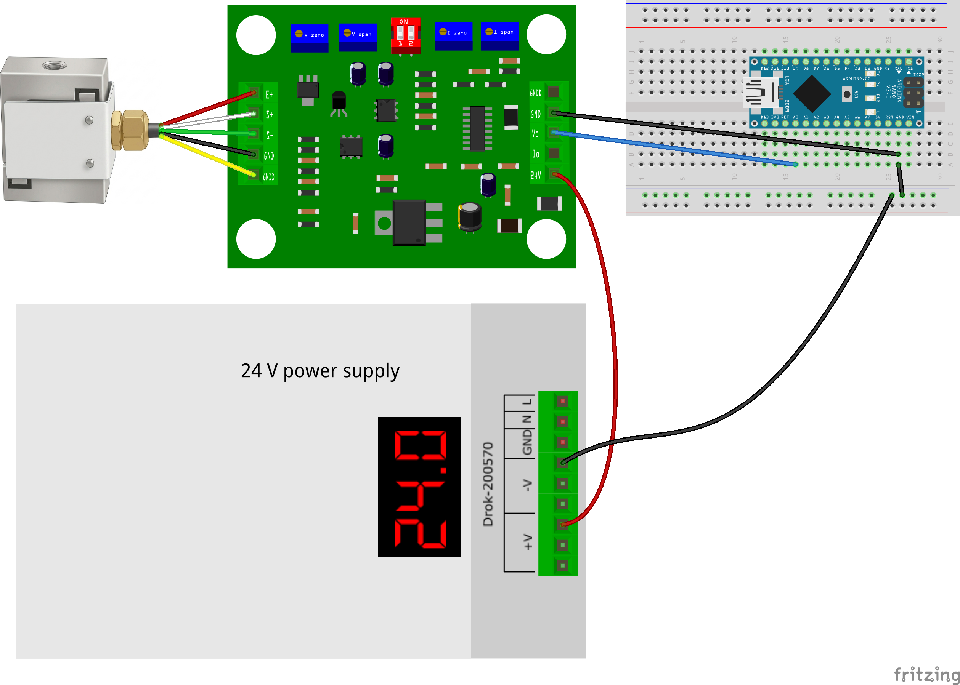
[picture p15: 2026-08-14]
Build_Instruction/Wiring/Load_Cell_50kg_SetUp.png

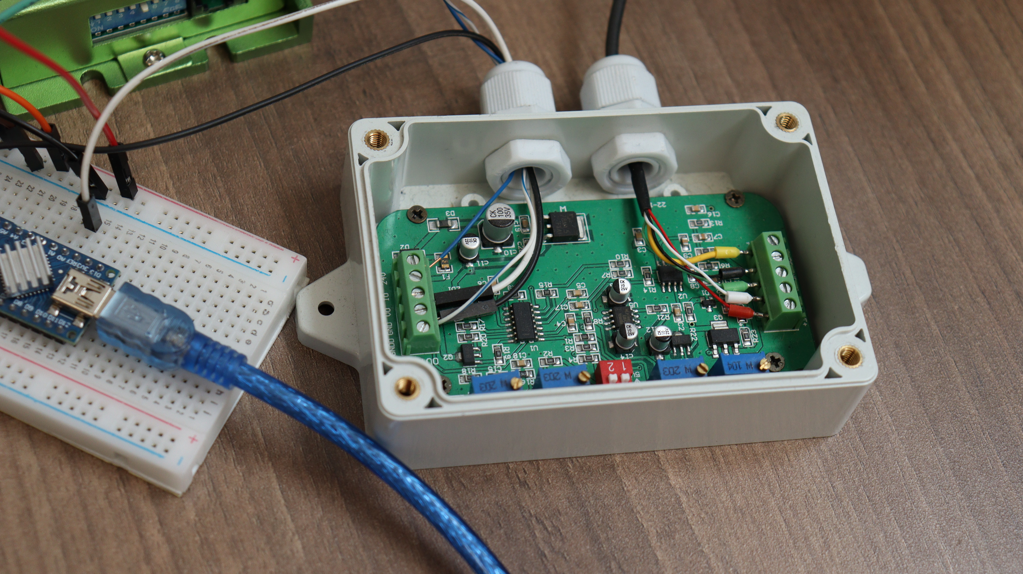
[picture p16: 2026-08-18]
Complements/System_Photos/Wiring_photos/LC50kg-1.JPG

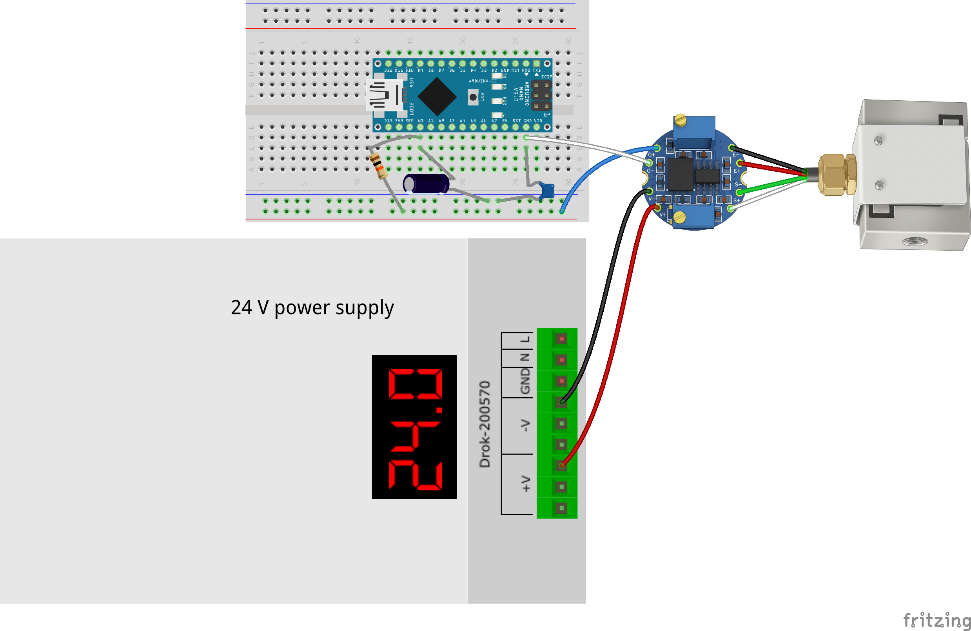
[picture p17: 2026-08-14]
Build_Instruction/Wiring/Load_Cell_1kg_SetUp.png

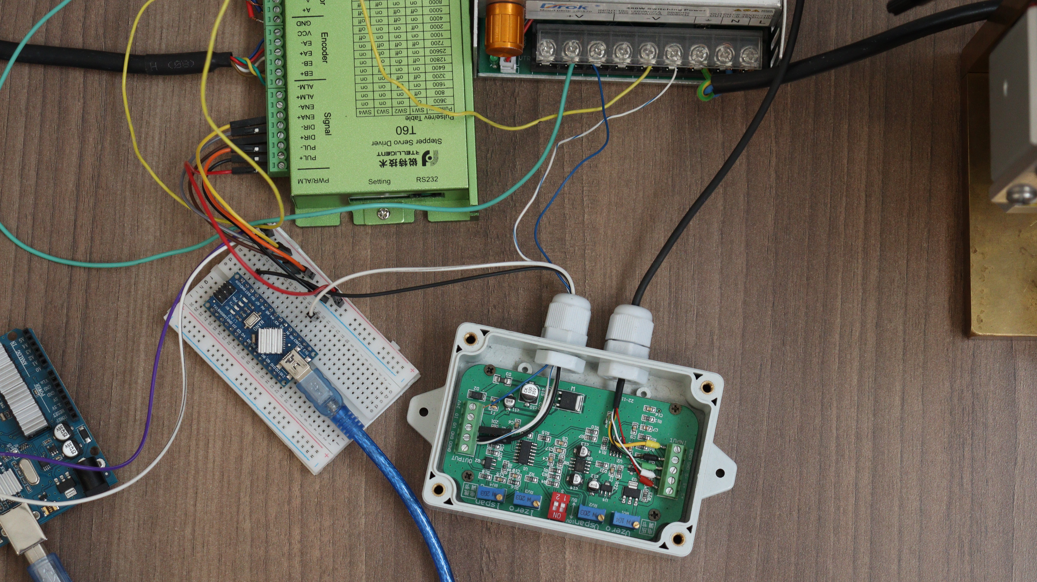
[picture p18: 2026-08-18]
Complements/System_Photos/Wiring_photos/LC50kg-3.JPG

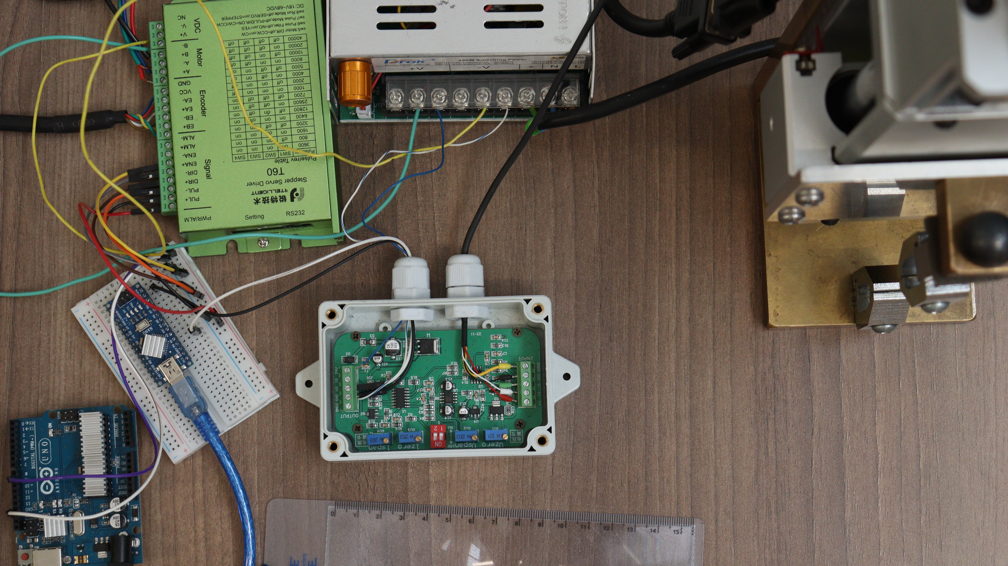
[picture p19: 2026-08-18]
Complements/System_Photos/Wiring_photos/LC50kg-4.JPG

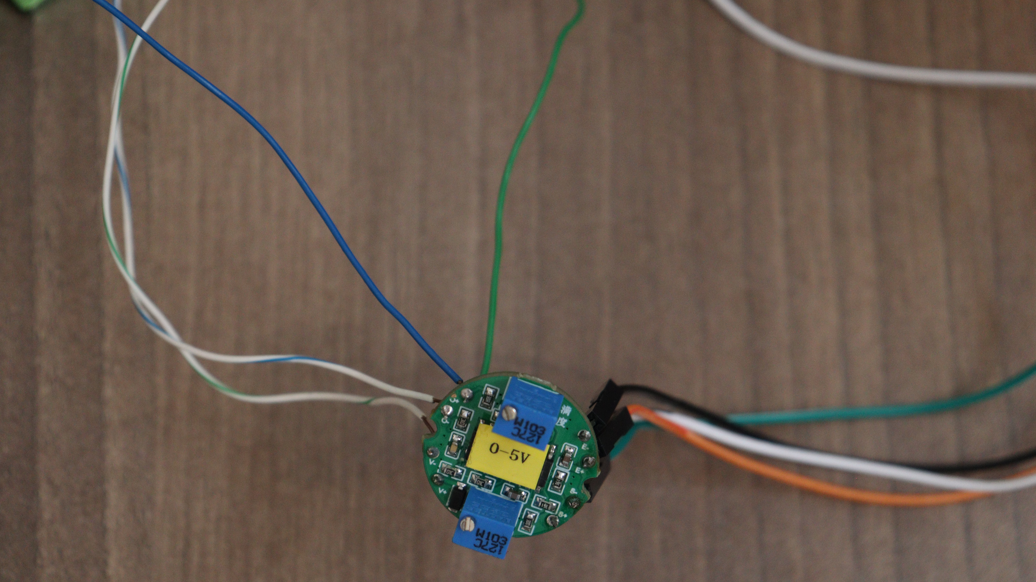
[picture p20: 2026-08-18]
Complements/System_Photos/Wiring_photos/LC1kg-3.JPG

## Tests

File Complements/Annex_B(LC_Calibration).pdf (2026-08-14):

Annex B1: Characterization of the 50 Kg Load Cell.

### 1. Introduction

This annex outlines the methodology employed to characterize the 50 Kg load cell integrated into the machine. The analysis includes the determination of the relationship between the applied force and the output signal, as well as the evaluation of linearity on the working range. The results ensure the accuracy of measurements obtained during experimental testing.

### 2. Materials and Methods

### 2.1. Equipment Used

- Load cell: Model DYLY106, with a maximum nominal capacity of 50 kg with a nominal output of 2.0mV/V, and an accuracy of +/- 0.1%.
- Load Cell Amplifier Transmitter: A WXD-D70 (JY-S60) model was selected, optimized for this kind of load cell. The device accepts an input signal with sensor sensitivity 2.0 mV/V up to 20mV and provides a DC output of 0–5V / 0–10 V / 4–20 mA
- Power supply: 24 V.
- Data acquisition system: Arduino-based interface with custom characterization software.
- A vertical press of initial compression load of 4.04 Kg.
- A hook of 0.76 Kg.
- Calibration standards: A set of precision weights of 1, 2, 4, and 10 Kg, previously verified using a digital calibrated scale (OHAUS Ranger 3000).


Fig. 1. Hardware for load cell characterization.

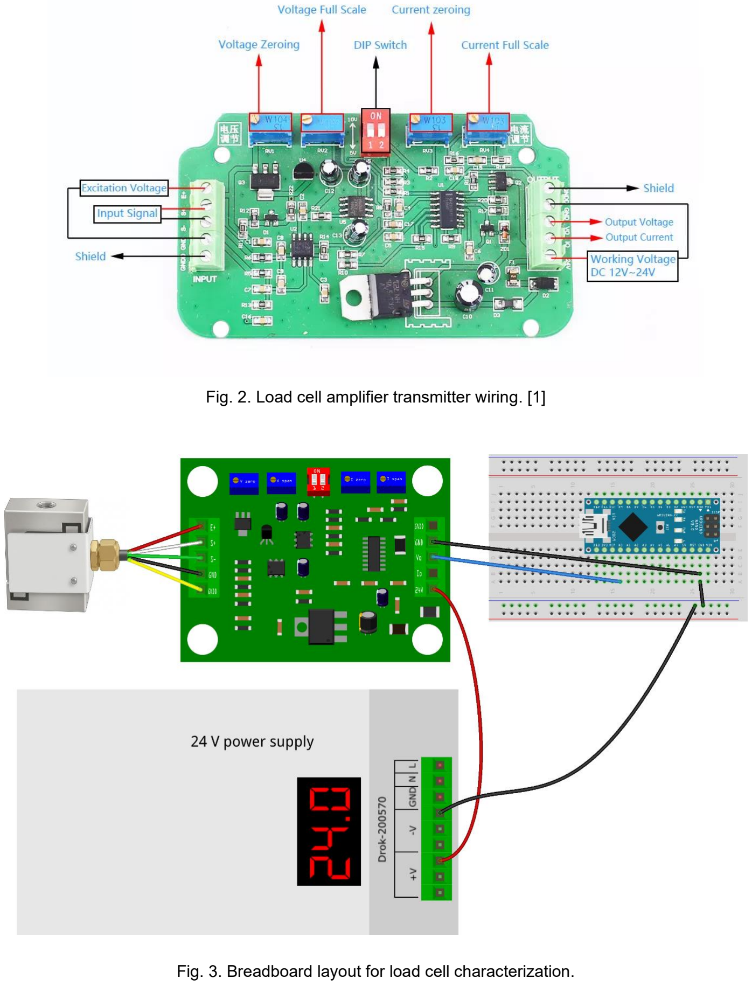
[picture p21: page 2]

Fig. 2. Load cell amplifier transmitter wiring. [1]

Fig. 3. Breadboard layout for load cell characterization.

### 2.2. Experimental Procedure

Following the wiring instruction of all the components, the load cell was wired to the amplifier and the Arduino Nano board, who was connected to a PC, for data acquisition (See Fig. 1 to 3).
A vertical traction to compression system was implemented, incorporating a suspension mechanism and the press. Then Incremental loads were applied using the calibration weights, ascending to the load cell’s 80% maximum capacity. For each measurement, the output voltage was recorded (See Fig. 4).

The span voltage calculation, as provided by ATO in the Load Cell Transmitter User Manual, was applied [2]:

Span voltage = Object weight / Load Cell capacity * 5V

This formula was integrated into the Arduino-based data analysis software to generate the specific characterization detailed herein. Finally, the acquired data were fitted using linear regression.

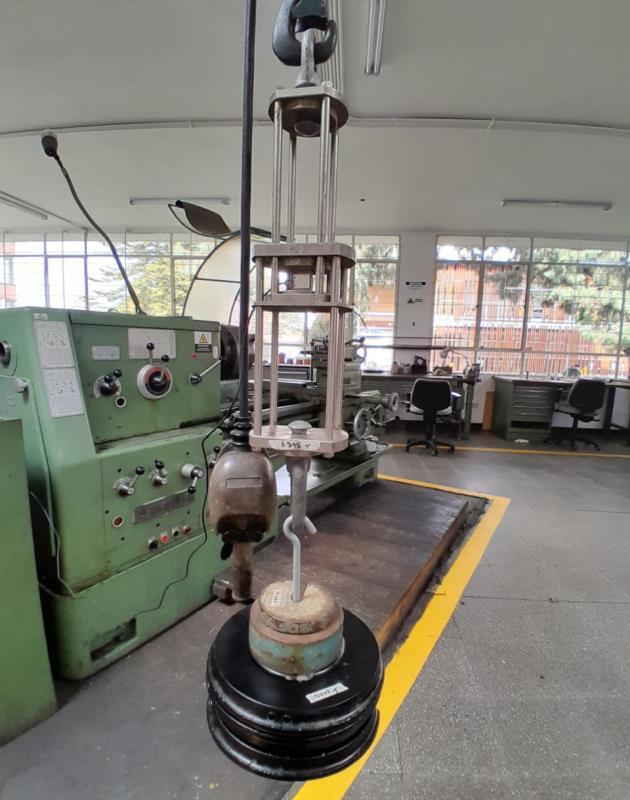
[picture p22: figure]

Fig. 4. Gradual increment of calibration weights.

### 3. Results

The characterization provided the relationship between the output voltage and vs the weight load applied, also confirms that the load cell meets the precision and repeatability requirements necessary for the project.


Fig. 5. Linear fit for the output voltage vs the weight.

As it can be seen in the Fig. 5, the ratio of Output voltage/Load is 0.1002 V/kgf or 0.1002 V/kg +/- 1%. Doing the conversion to N/V (adjusted for Bogotá’s gravitational acceleration of 9.774 m/s²), it becomes 97.54 N/V +/- 3%, which it’s the final ratio that going to be set into the Arduino-based data acquisition software. The R-square is 1 in the evaluated range, so it proves the linearity of the load cell.

Either for the characterization or the experiments, it is recommended not to exceed the 90% of the maximum load capacity to avoid losses on the measurement accuracy or linearity or even mess up the load cell.

Annex B2: Characterization of the 1 Kg Load Cell.

### 1. Introduction

The previous section presented the specifications for characterizing the 50 kg load cell. The methodology followed here is broadly analogous to that described therein, with a few changes described below.

### 2. Materials and Methods

### 2.1. Equipment Used

- Load cell: S-type Miniature Model DYLY-106, with a maximum capacity of 1 kg with a nominal output of 1.0mV/V, and an accuracy of +/- 1%
- Load cell signal amplifier: An Shitailinge voltage signal transmitter model was selected, optimized for this application due to its high performance. The device accepts an input signal of 0.8–3 mV and provides a DC output of 0–5V.
- Power supply: 24 V.
- Data acquisition system: Arduino-based interface with custom characterization software.
- Calibration standards: A set of precision weights (5g, 10g, 20g, 50g, 99g, 100g, 998g), previously verified using a digital scale (OHAUS Scout Pro).

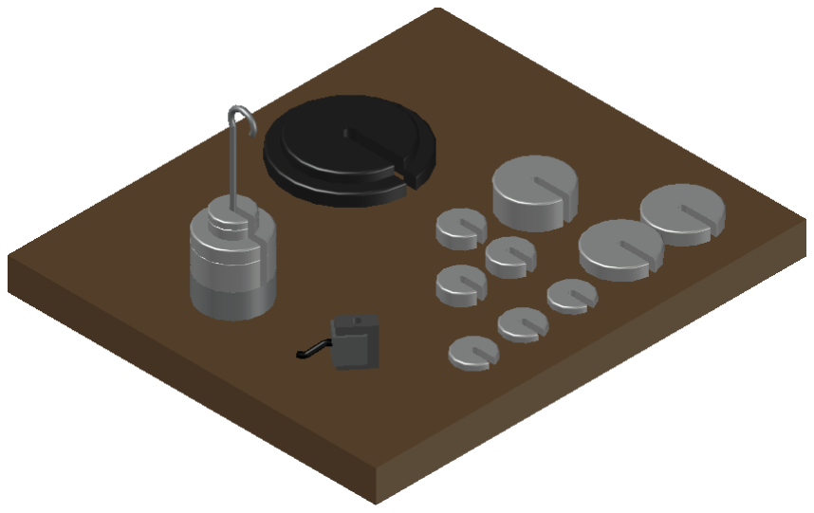
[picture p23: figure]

Fig. 6. 1kg load cell characterization assembly.

### 2.2. Experimental Procedure

This time, the load cell was characterized under direct compressive loading conditions, where calibration weights were progressively added in incremental steps, in contrast to the tensile-compression loading methodology described in Appendix B1 (See Fig. 6 and Fig. 7). The load cell was wired to the signal amplifier and subsequently to the Arduino Nano board, which was connected to a PC for data acquisition. As in the previous characterization, wires and connections were made following the wiring instruction of all the components, shown in Fig. 8 and Fig. 9.

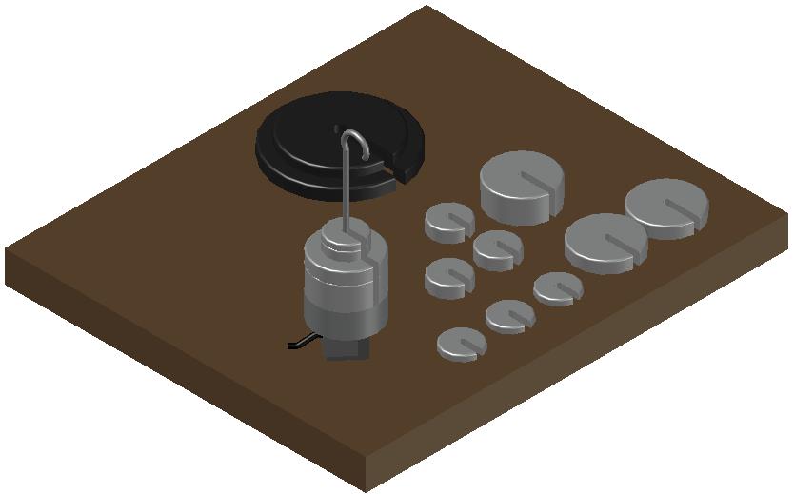
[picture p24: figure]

Fig. 7. Gradual increment of calibration weights on the 1kg Load Cell

The span voltage calculation, as provided by ATO in the Load Cell Transmitter User Manual, was applied [2]:

Span voltage = Object weight / Load Cell capacity * 5V

The same Arduino software framework from the initial calibration was maintained, apart from the modified span voltage calculation mentioned above. As with the previous tests, linear regression analysis was applied.

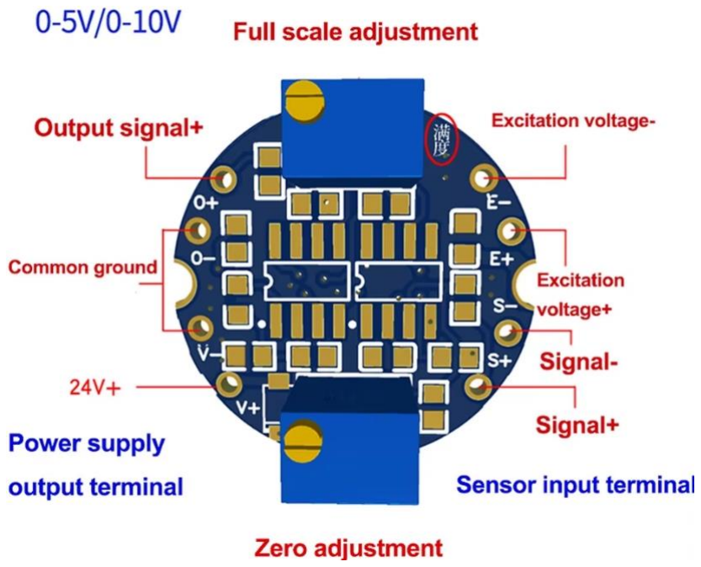
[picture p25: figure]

Fig. 8. Load cell signal amplifier wiring. [3]

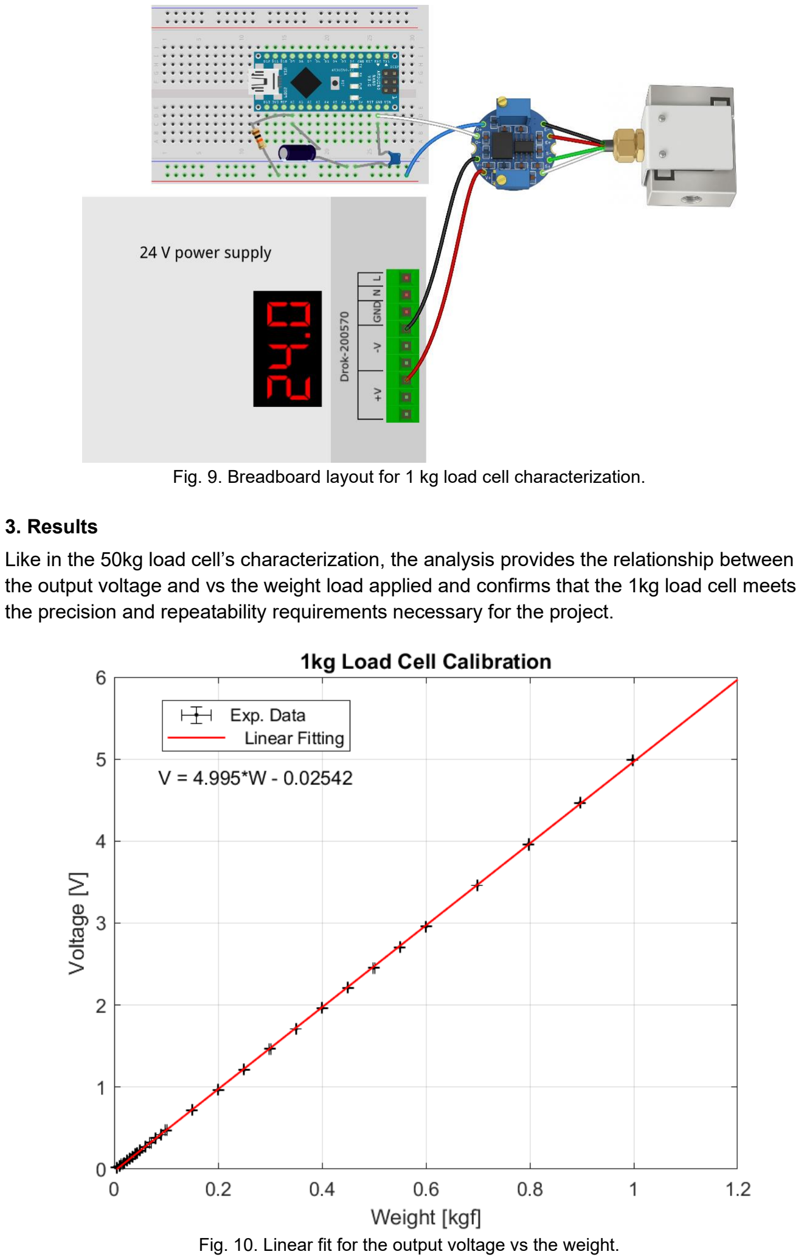
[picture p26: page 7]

Fig. 9. Breadboard layout for 1 kg load cell characterization.

### 3. Results

Like in the 50kg load cell’s characterization, the analysis provides the relationship between the output voltage and vs the weight load applied and confirms that the 1kg load cell meets the precision and repeatability requirements necessary for the project.

Fig. 10. Linear fit for the output voltage vs the weight.

As it can be seen in the Fig. 10., the ratio of Output voltage/Load is 4.995 V/kgf or 4.995 V/kg +/- 2%. Doing the conversion to N/V (adjusted for Bogotá’s gravitational acceleration of 9.774 m/s²), it becomes 1.96 N/V +/- 5%, which it’s the final ratio that going to be set into the Arduino-based data acquisition software. The R-square is 0.9999 in the evaluated range, so it proves the linearity of the load cell.

For both the characterization and the experiments, it is recommended not to exceed 95% of the maximum load capacity, to avoid losses in measurement accuracy or linearity, or even damage to the load cell. It’s critically important to not exceed the input power supply, since the signal amplifier could easily burn out.

# References:

[1] “Load Cell Transmitter JY-S60,” Micro Robotics, [Online]. Available: https://www.robotics.org.za/JY-S60-12V. [Accessed 31 July 2026].
[2] ATO international, “Load Cell Transmitter User Manual,” [Online]. Available: Load-celltransmitter-user-manual-ATO-LCTR-OA (https://www.ato.com/Content/doc/Load-celltransmitter-user-manual-ATO-LCTR-OA.pdf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). [Accessed 31 July 2026].
[3] STAILNGE-Shitailinge, “Load Cell Amplifier Signal Transmitter Module Current 4-20mA 0-10V Output RS485 Modbus RTU Tension Compression Sensor,” AliExpress Alibaba Group, [Online]. Available: Load Cell Amplifier Signal Transmitter Module Current 4-20mA 0-10V Output RS485 Modbus RTU Tension Compression Sensor - AliExpress 502 (https://es.aliexpress.com/item/1005008772095526.html?scm_id=1007.40196.442820.0&scm-url=1007.40196.442820.0) (https://n9.cl/h2mejt). [Accessed 31 July 2026].

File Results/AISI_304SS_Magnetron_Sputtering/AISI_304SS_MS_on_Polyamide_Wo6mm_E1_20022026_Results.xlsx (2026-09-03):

Timestamp | Frame | Arduino Lecture | Force(N) | Stress (Pa) |  |  | Lucas-Kanade(px) | Strain-LK(mm/mm) | Lucas-Kanade(mm) | BC=before the main cycle
2026-02-20 20:01:22.139115 | 0 | 4.74 | 2.25972 | 7000371.747 | ReferenceBC | Lo | 915.067749 | 1 | 18.33542219 | DC=during the main cycle
2026-02-20 20:01:22.529555 | 0 | 4.86 | 2.31693 | 7177602.23 | ReferenceDC | No lecture with the LK Software | Null | Null | Null
2026-02-20 20:01:22.764282 | 1 | 5.02 | 2.39321 | 7413909.542 |  |  | 0 | 0 | 0
2026-02-20 20:01:23.002085 | 2 | 5.2 | 2.47902 | 7679739.777 |  |  | 0.1339111328 | 0.0001463401294 | 0.002683208057
2026-02-20 20:01:23.161399 | 3 | 5.22 | 2.48856 | 7709293.68 |  |  | 0.2207641602 | 0.0002412544431 | 0.00442350207
2026-02-20 20:01:23.322570 | 4 | 5.22 | 2.48856 | 7709293.68 |  |  | 0.17578125 | 0.0001920964324 | 0.00352216919
2026-02-20 20:01:23.487472 | 5 | 5.4 | 2.57437 | 7975123.916 |  |  | 0.1635742188 | 0.0001787564024 | 0.003277574108
2026-02-20 20:01:23.655306 | 6 | 5.34 | 2.54577 | 7886524.164 |  |  | 0.4949951172 | 0.0005409382177 | 0.009918330602
2026-02-20 20:01:23.906127 | 7 | 5.46 | 2.60297 | 8063723.668 |  |  | 0.6851196289 | 0.0007487091853 | 0.01372789901
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

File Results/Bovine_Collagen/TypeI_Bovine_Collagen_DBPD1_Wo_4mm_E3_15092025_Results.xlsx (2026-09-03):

Timestamp | Desplazamiento (px) | Arduino Lecture | Force (N) | Stress(Pa) |  |  | Lucas-Kanade (px) | Lucas-Kanade(mm) | Strain(mm/mm) | BC=before the main cycle
2025-08-08 18:19:31.591578 | 0 | 0 | 0 | 0 | ReferenceBC - Reference take all zero due to the ports werent ready | Lo | 336.2915344 | 12.99391185 | 1
2025-08-08 18:19:32.106434 | 1.45216518 | 1.04 | 0.01012 | 2530 |  |  | 0.9274902344 | 0.03583713865 | 0.002757994595
2025-08-08 18:19:32.648495 | 1.742514899 | 0.98 | 0.00954 | 2385 |  |  | 2.113891602 | 0.08167830088 | 0.006285890025
2025-08-08 18:19:33.197281 | 2.813021849 | 1.04 | 0.01012 | 2530 |  |  | 2.669433594 | 0.1031437942 | 0.007937855463
2025-08-08 18:19:33.763479 | 2.84691966 | 1.02 | 0.00993 | 2482.5 |  |  | 3.298034668 | 0.127432205 | 0.009807070147
2025-08-08 18:19:34.277119 | 4.132623315 | 1.04 | 0.01012 | 2530 |  |  | 3.968292236 | 0.1533301741 | 0.01180015501
2025-08-08 18:19:34.808385 | 4.071268328 | 1.02 | 0.00993 | 2482.5 |  |  | 4.81918335 | 0.1862076122 | 0.01433037367
2025-08-08 18:19:35.334598 | 4.438953397 | 1.04 | 0.01012 | 2530 |  |  | 5.336608887 | 0.2062003302 | 0.01586899562
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

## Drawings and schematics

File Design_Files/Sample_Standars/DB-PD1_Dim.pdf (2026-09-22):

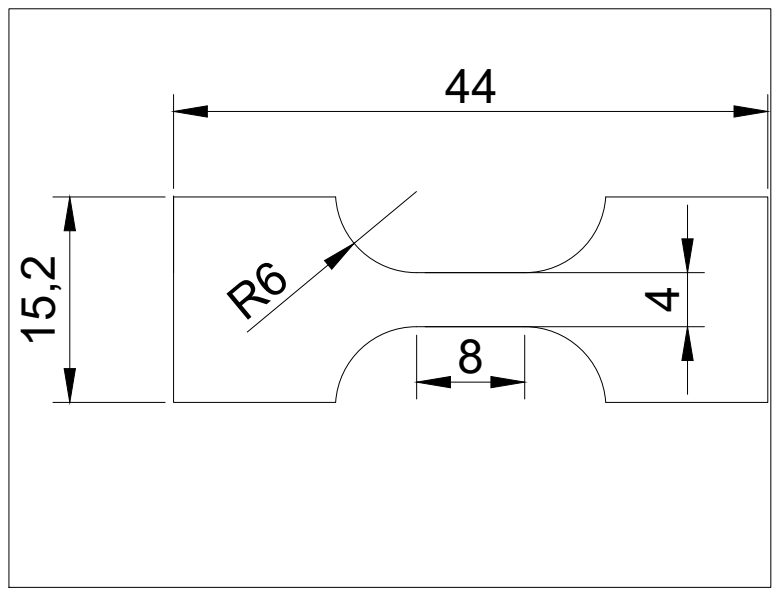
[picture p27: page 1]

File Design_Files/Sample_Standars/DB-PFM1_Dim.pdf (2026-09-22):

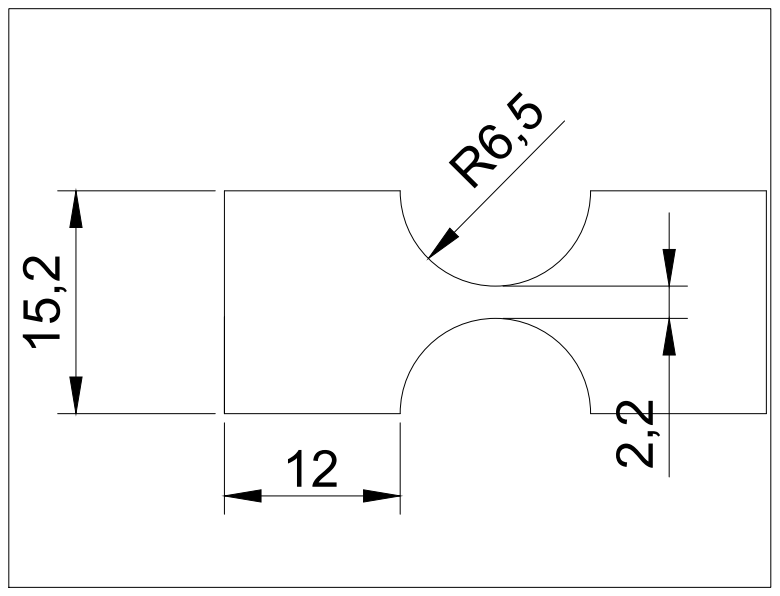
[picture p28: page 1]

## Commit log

2026-08-11 1st Documentation Load
    Here is some of the desing files, the .txt and .pdf of the project's lincenses, and the OSHWA Licenses Facts.
    [Actuator_base.dwg, Camara_macro.dwg, Camara_micro_E5X.dwg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]
2026-08-13 Main Results Bovine Collagen
    Here is the main results of essay number 3 of bovine collagen scaffold type 1. Were used the Short versión #5 of the macro video record for the DIC and Optical Flow analysis with OpenCV.
2026-08-14 2nd Documentation upload and folder name corretion
    Here I put the wiring setup for the load cell of 1kg, 5kg, and for the motor setup, and made the folder name corretion
    [Actuator_base.dwg, Camara_macro.dwg, Camara_micro_E5X.dwg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]
2026-08-14 3rd Documentation Upload
    Here we put some of the Research Outputs of the project, a short version of the Operation Instrutions, and some complements like calibration annex, 3D models of the posible setups and photos
    [Camera_Support.stl, Camera_macro_Barlow.dwg, Camera_micro_E5X.dwg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]
2026-08-18 4th Documentation upload
    Here I put some of the references and research outputs, photos of the system, some photo of the wiring, calibration photos in .tif, update the results and create some new folders for all of them.
2026-08-19 Update Bill_of_materials.md
    Typographical errors were corrected and the 5kg load cell line was commented out. The total price was also modified.
2026-08-24 Update README.md
    Inclusion of device images
2026-08-25 Update README.md
    Inclusion of device's and license's images
2026-09-03 5th Documentation Upload
    Here rename some files, and add all the .xlsx of the results, also load almost every video record result, and reorganized the PLA and Biopolymer folders to divide the essays for sample standart.
    In next days Im gonna finish the results upload, and organization.
    [AISI_304SS_MS_on_Polyamide_Wo6mm_E1_20022026_Results.xlsx, CornStarch_Biopolymer_DBPFM1_Wo_2,2mm_E1_20022026_Results.xlsx, Cornstarch_Biopolymer_DBPD1_Wo_4mm_E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]
2026-09-18 Update Bill_of_materials.md
    I fixed an error that was making the BOM dont look like a table.
2026-09-22 6th Documentation Upload
    In this upload, I put the missing .dwg files, fix and change some os the sample standart files, and made a few correction in the operation instruction doc. Finally, putted a new 3D model photo to the complement folder.
    [DB-PD1_Dim.dwg, DB-PFM1.stl, DB-PFM1_Dim.dwg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]
2026-09-24 Update LICENSE
    intento de actualización de licencias.
2026-10-12 7th Documentation Upload
    Here I fixed the issue in the Software Folder, create 2 diferente subfolders. One with the realese candidate version of the code set, and another with the current version.
2026-10-12 Main code without ORB
    Here I put a version of the RT code (v.1.1.0-b.1), where is not used the real time analisis with ORB, just made the reading of the sensor data sinchronized with the reacording of the cameras.
2026-11-09 Update Bill_of_materials.md
    BOM's final changes
2026-11-12 10th documentation upload
    Just taked a few screnshot of the 3D models of the cameras setups, migth be useful for the BI.
